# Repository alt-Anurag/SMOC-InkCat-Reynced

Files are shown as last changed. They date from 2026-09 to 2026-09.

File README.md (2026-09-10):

# InkCat — SMOC: A Modular, Self-Calibrating SCARA Robot

**A 5-DOF Self-Calibrating Modular SCARA bot built around a distributed embedded control network, continuous self-calibrating sensor fusion, and a simulation-first (Unity3D/ROS2) development pipeline.**

InkCat is a proof-of-concept precision robotic arm — not a hobby kit adaptation. Every layer of the stack was designed from scratch: the SolidWorks CAD kinematic chain, two custom PCB families (a supervisory controller and a distributed per-joint actuator board), a MATLAB/Simulink closed-loop control architecture validated against a Simscape Multibody model, and a Unity3D + ROS2 + OpenCV vision pipeline for perception-guided pick-and-place.

The long-term goal is ambitious by design: take this arm from a 3D-printed, PLA-bodied proof of concept to a rigid, millimeter-precision manipulator capable of tasks like PCB-grade component placement and even in-house PCB fabrication steps — the kind of precision work usually reserved for industrial SCARA arms costing orders of magnitude more.

<p align="center">
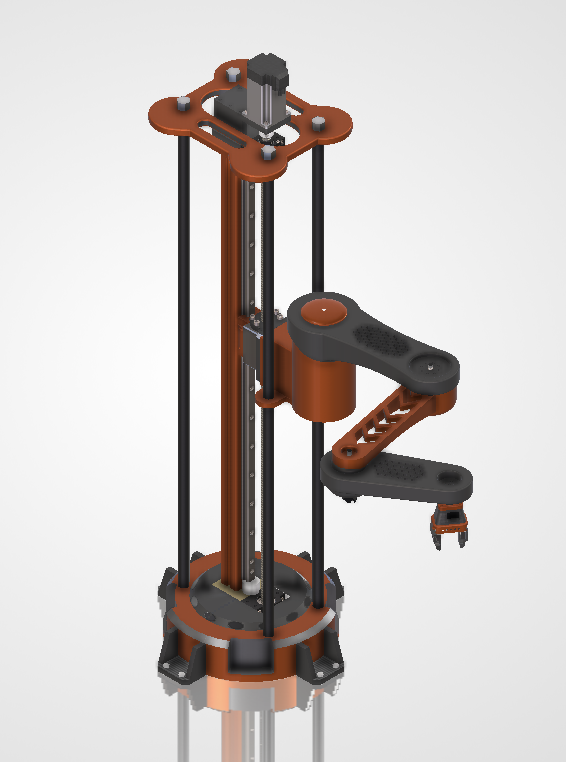
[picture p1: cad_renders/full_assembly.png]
InkCat full assembly render
  
</p>

---

## Table of Contents

- [Project Status](#project-status)
- [Why This Project Is Different](#why-this-project-is-different)
- [Tech Stack](#tech-stack)
- [System Architecture](#system-architecture)
- [Mechanical Design & CAD](#mechanical-design--cad)
  - [Kinematic Configuration](#kinematic-configuration)
  - [Structural Design](#structural-design)
  - [Material Strategy — Prototype vs. Deployment](#material-strategy--prototype-vs-deployment)
- [Electronics — Distributed Control Architecture](#electronics--distributed-control-architecture)
  - [Vesper ONE — Main Supervisory Controller](#vesper-one--main-supervisory-controller)
  - [FluxCruiser — Per-Joint Actuator Node](#fluxcruiser--per-joint-actuator-node)
  - [Sensor Fusion & Self-Calibration](#sensor-fusion--self-calibration)
- [Control Loop — MATLAB/Simulink Architecture](#control-loop--matlabsimulink-architecture)
- [Software & Perception Stack](#software--perception-stack)
- [Power Architecture](#power-architecture)
- [Repository Structure](#repository-structure)
- [How to Replicate / Build On This Project](#how-to-replicate--build-on-this-project)
- [Known Limitations](#known-limitations)
- [Roadmap](#roadmap)
- [Reference Material](#reference-material)
- [Credits](#credits)

---

## Project Status

This repository currently documents a **validated proof of concept**: the CAD kinematic design is complete and rendered, the control loop is validated in MATLAB/Simulink against a Simscape Multibody model, and both PCBs (Vesper ONE and FluxCruiser) are schematic-complete CAD designs. Firmware, ROS 2 nodes, and ML/vision scripts are **actively in development** and will be added to [`firmware/`](firmware/) as they're built and tested — see the disclaimers in each firmware subfolder for current status.

| Layer | Status |
|---|---|
| Mechanical CAD (SolidWorks) | ✅ Complete — full assembly modeled, rendered, exportable (STL/GLB/STEP) |
| Control loop (MATLAB/Simulink) | ✅ Validated in simulation (Simscape Multibody + EKF) |
| PCB schematics (Vesper ONE, FluxCruiser) | ✅ Schematic-complete, pre-fabrication |
| STM32 firmware | 🚧 In development — see [`firmware/stm32/`](firmware/stm32/) |
| ROS 2 / perception nodes | 🚧 In development — see [`firmware/ros2/`](firmware/ros2/) |
| ML / vision scripts | 🚧 In development — see [`firmware/ml_models/`](firmware/ml_models/) |
| Physical fabrication & assembly | 🔜 Planned next phase |

---

## Why This Project Is Different

* **Distributed embedded architecture:** Instead of putting the entire control stack on a single MCU, InkCat divides the workload between a supervisory STM32H743 (Vesper) and three STM32G431 actuator nodes (FluxCruiser). Vesper handles tasks such as state estimation and trajectory planning, while each actuator board runs the motor control locally for fast and predictable response.

* **Continuous self-calibration:** A key part of InkCat is keeping the robot's internal model accurate while it is operating. Joint encoders, a base-offset optical sensor, a magnetic Z-height encoder, and IMUs on the actuator nodes provide multiple measurements that can be combined through a recursive state estimator. This is intended to account for things such as mechanical offsets and drift without requiring the arm to be manually recalibrated between runs.

* **Simulation-first development:** The control system was developed and tested in MATLAB/Simulink using a Simscape Multibody model of the arm. This includes the Computed Torque Controller derived from the Euler-Lagrange formulation. In parallel, a Unity3D + ROS2 digital twin is used to test the vision and perception pipeline under different sensor and lighting conditions before moving to the physical setup.

* **Custom controller and actuator PCB architecture.** Vesper is the central controller board and handles the non-actuator sensors and external communication interfaces, including Ethernet, USB-C, and CAN-FD. The FluxCruiser boards handle the individual joints, with a dedicated Trinamic TMC9660 gate driver used for the motor-control stage.

* **Staged mechanical development:** The mechanical design is intended to work across different stages of development. The same CAD platform can first be used for an FDM-printed PLA prototype to validate the kinematics and control system, and later transition to a CNC-machined aluminum/steel version without requiring a complete structural redesign.

* **Designed around precision from the start:** InkCat is being developed with millimeter-level pick-and-place as a target, with applications such as PCB component handling and, eventually, automated PCB manufacturing processes in mind. Precision is therefore considered during the mechanical, sensing, and control design rather than being added after the basic arm is already functional.

---

## Tech Stack

| Layer | Choice |
|---|---|
| Mechanical CAD | SolidWorks 2026 |
| Supervisory Controller | STM32H743ZIT6 (Arm Cortex-M7, up to 480 MHz) — "Vesper ONE" |
| Actuator Node MCU (×3) | STM32G431 — "FluxCruiser" |
| Motor Driver / FOC Engine | Trinamic TMC9660 (×3, one per joint) |
| Z-Axis Stepper Driver | Trinamic TMC5160 (on Vesper) |
| Joint Encoders | SIKO AS5600 absolute magnetic encoder (×3) |
| Base Offset Sensor | PixArt PMW3389 high-precision optical motion sensor |
| IMUs | ADI ADIS16470-class / ICM-45686 6-axis (per actuator node) |
| Communication | CAN-FD (MAX33012EASA+), Ethernet (ADIN1200 PHY), USB Type-C, SPI, UART, I²C |
| Control Design | MATLAB/Simulink 2025, Simscape Multibody, Extended Kalman Filter |
| Control Law | Computed Torque Control (Euler-Lagrange), PD feedback, quintic polynomial trajectory planning, ADRC (planned for embedded target) |
| Simulation / Digital Twin | Unity3D + ROS 2 |
| Computer Vision | OpenCV (HSV segmentation, monocular projection) |
| PCB Design | Altium Designer 2025 |
| Motor / Magnetics Design | Ansys Maxwell |
| Prototype Material | PLA (FDM) / Carbon-Fiber-Reinforced PLA |
| Deployment Material | Aluminium 6061-T6 (links, column), steel (base, joint shafts, fasteners) |

---

## System Architecture

```
                         ┌─────────────────────────────────────────┐
                         │      VESPER ONE (STM32H743ZIT6)         │
   Vision (Ethernet/USB) │      Supervisory Controller             │
   ─────────────────────►│  • Sensor fusion (EKF/EWMA)             │
                         │  • Self-calibration engine              │
   PMW3389 (base offset) │  • Inverse kinematics                   │
   ─────────────────────►│  • Quintic trajectory planning          │
                         │  • ADRC / high-level closed-loop control│
   MSC500 (Z-height)     │  • TMC5160 — Z-axis stepper drive       │
   ─────────────────────►│                                         │
                         └───────────────┬─────────────────────────┘
                                         │ CAN-FD
                ┌────────────────────────┼────────────────────────┐
                ▼                        ▼                        ▼
    ┌─────────────────────┐    ┌────────────────────┐    ┌────────────────────┐
    │  FluxCruiser #1     │    │  FluxCruiser #2    │    │  FluxCruiser #3    │
    │  (Shoulder)         │    │  (Elbow)           │    │  (Wrist)           │
    │  STM32G431 + TMC9660│    │ STM32G431 + TMC9660│    │ STM32G431 + TMC9660│
    │  + IMU + Encoder    │    │ + IMU + Encoder    │    │ + IMU + Encoder    │
    └─────────┬───────────┘    └─────────┬──────────┘    └─────────┬──────────┘
              ▼                          ▼                         ▼
         BLDC Motor                BLDC Motor              BLDC Motor / Gripper
         (Shoulder)                 (Elbow)                  (Wrist + Gripper)
```

Vesper is the single point of contact for every non-actuator sensor and all external communication — no other board in the system carries a direct external connection. The three FluxCruiser nodes handle only their local joint's current/velocity/position loop and stream raw encoder/IMU data back to Vesper over CAN-FD as ground-truth feedback, independent of what was actually commanded.

---

## Mechanical Design & CAD

<p align="center">
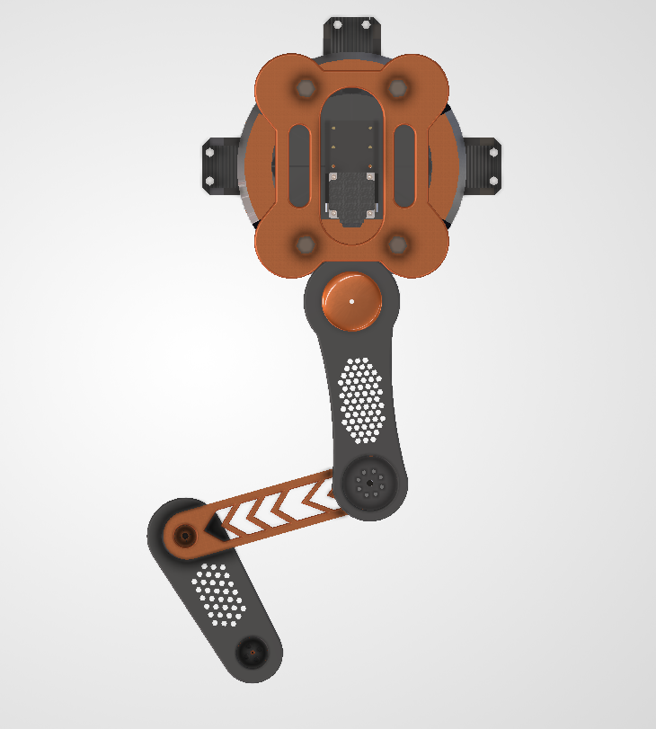
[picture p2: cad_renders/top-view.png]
Top view of arm reach
  
  &nbsp;&nbsp;
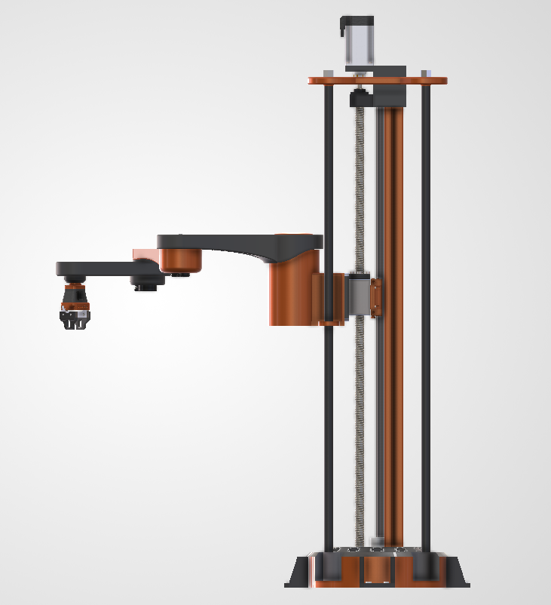
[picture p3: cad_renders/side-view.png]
Side view of column
  
</p>

### Kinematic Configuration

InkCat is a custom 5-degree-of-freedom desktop SCARA following a **Prismatic–Revolute–Revolute–Revolute–Prismatic (P-R-R-R-P)** joint chain. This is the classic SCARA layout — high stiffness along the vertical Z-axis, selective compliance in the horizontal X-Y plane — extended with a wrist revolute joint and a rack-and-pinion parallel-jaw gripper for full end-effector orientation and controlled grasp force.

| Joint | Type | Actuation | Primary Function |
|---|---|---|---|
| DOF 1 — Z Axis | Prismatic | Lead-screw linear actuator + linear guide rail | Vertical approach, pickup, placement, height adjust |
| DOF 2 — Shoulder | Revolute | BLDC motor, vertical axis | Primary arm sweep, workspace coverage |
| DOF 3 — Elbow | Revolute | BLDC motor, vertical axis | Reach extension, fine positioning |
| DOF 4 — Wrist | Revolute | BLDC motor, vertical axis | End-effector orientation, placement alignment |
| DOF 5 — Gripper | Prismatic | Rack-and-pinion, parallel jaws | Grasp, release, precision manipulation |

The resulting workspace is cylindrical: vertical reach is set by the Z-axis stroke, and horizontal reach by the two-link arm's combined length — giving the arm the SCARA-defining trait of being naturally forgiving for vertical insertion tasks (PCB/connector-style assembly) while remaining precisely positioned laterally.

### Structural Design

<table>
  <tr>
    <td width="260" align="center">
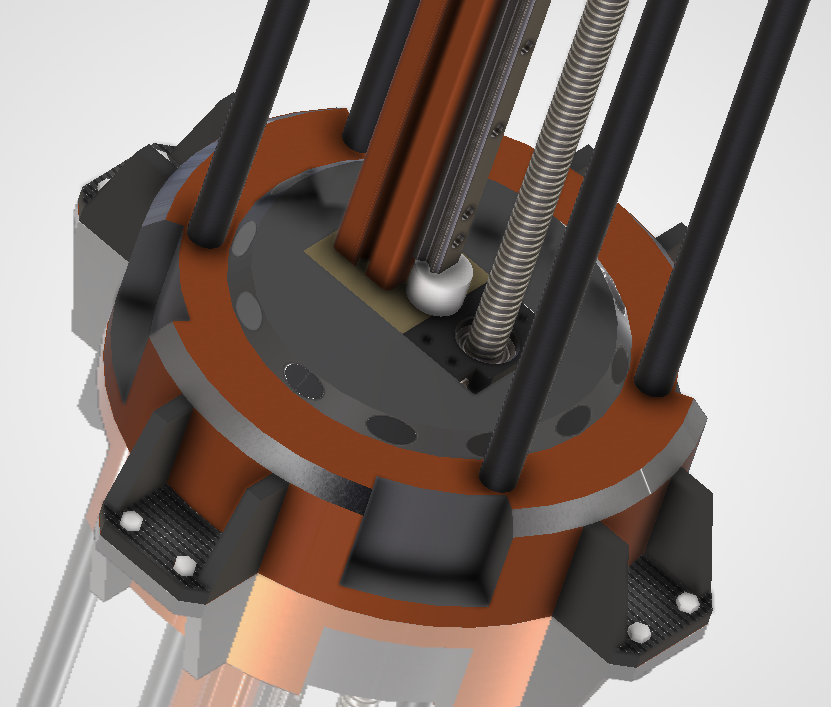
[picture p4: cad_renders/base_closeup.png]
      <br>
      <sub><b>Base & Z-column</b></sub>
    </td>
    <td>The base is an enclosed housing with a removable cover, internally compartmentalized for the PCB, motor drivers, wiring harnesses, and power electronics. Keeping all electronics inside the base lowers the overall center of gravity and keeps the arm's kinematic assembly above it undisturbed during maintenance. The vertical column integrates the linear guide rail, lead screw, drive motor enclosure, and sliding carriage into one rigid structural member — it has to carry axial load and resist the bending moment of the fully extended arm simultaneously, which drove the choice of a ribbed, large-cross-section profile.</td>
  </tr>
  <tr>
    <td width="260" align="center">
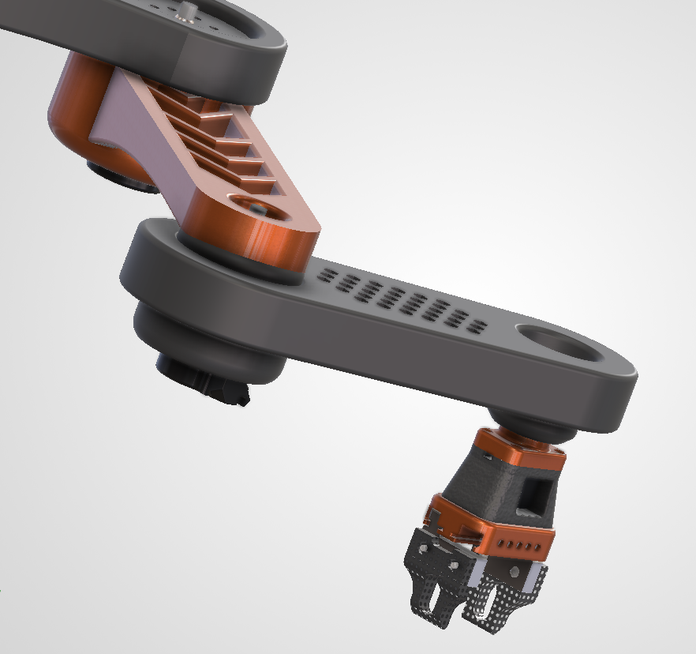
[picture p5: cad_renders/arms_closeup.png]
      <br>
      <sub><b>Upper arm & fore-arm links</b></sub>
    </td>
    <td>Both arm links use a hollow, ribbed shell geometry with rounded edges and a deliberately large bending depth. This is a weight-optimization strategy — removing material from the neutral bending axis while retaining depth preserves stiffness-to-weight ratio, which directly reduces the rotational inertia the shoulder and elbow BLDC motors have to overcome during acceleration.</td>
  </tr>
  <tr>
    <td width="260" align="center">
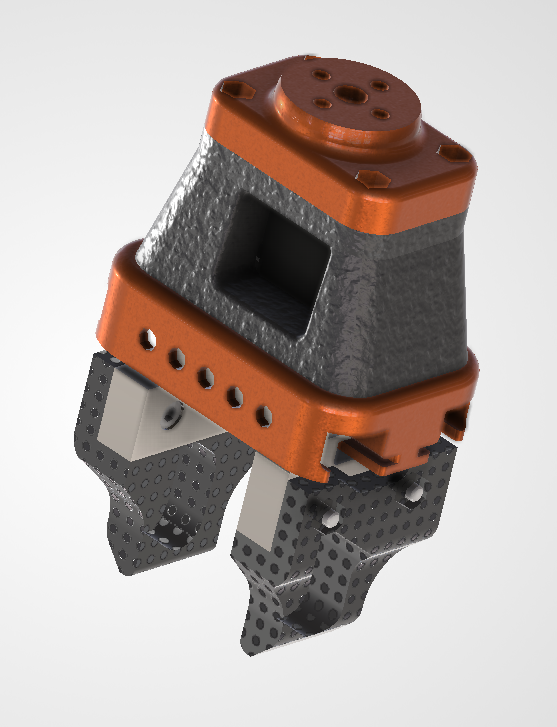
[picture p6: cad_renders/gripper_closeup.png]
      <br>
      <sub><b>Wrist & gripper</b></sub>
    </td>
    <td>The wrist is a compact rotational stage that orients the gripper before grasp. The end effector is a parallel-jaw gripper actuated through a rack-and-pinion mechanism, chosen for symmetric jaw travel, positive mechanical engagement, and repeatable grip force — suited to PCB handling, small mechanical parts, and lab-sample manipulation.</td>
  </tr>
  <tr>
    <td width="260" align="center">
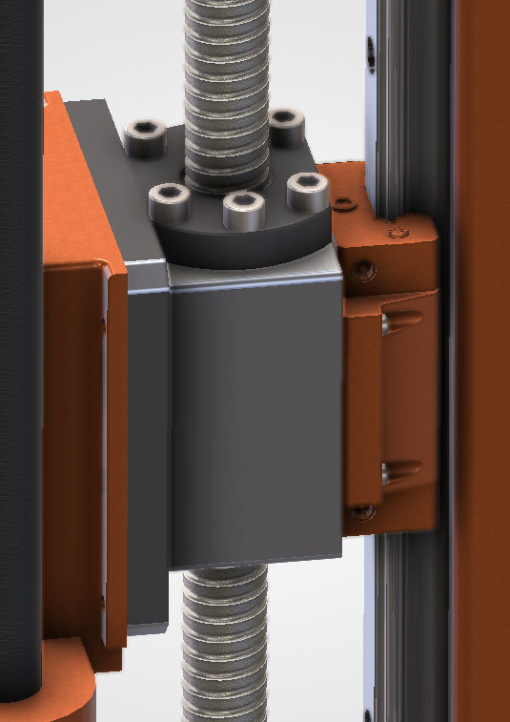
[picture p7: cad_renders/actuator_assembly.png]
      <br>
      <sub><b>Z-axis actuator detail</b></sub>
    </td>
    <td>Close-up of the lead-screw carriage and linear guide interface — the load path the entire arm hangs off of. Precision here directly bounds the vertical repeatability of the whole manipulator.</td>
  </tr>
</table>

**Design language:** the platform deliberately follows a hidden-actuator, minimal-fastener visual language — motor housings enclosed, fillets consistent across every structural part, symmetric arm proportions, and an orange-and-black color scheme meant to read as a finished product rather than a lab rig.

**Manufacturability:** the CAD is built as a serviceable modular assembly — independently swappable link components, fully enclosed electronics, and internal cable routing through the column and links — suited to FDM/SLA printing of the structural shells combined with off-the-shelf linear guides, lead screws, bearings, and fasteners for the motion-critical interfaces.

### Material Strategy — Prototype vs. Deployment

| Phase | Structural Components | Motion / Hardware Components |
|---|---|---|
| **Phase 1 — Prototype / Testing** | PLA (FDM 3D-printed): base shell, links, wrist housing, gripper jaws | Steel lead screw & linear rail, standard bearings, off-the-shelf BLDC motors and fasteners |
| **Phase 2 — Final Deployment** | Aluminium 6061-T6 (links & column, machined/CNC); steel (high-load base and joint interfaces) | Precision-ground steel lead screw, hardened linear rails, rubber gripper-jaw inserts, sealed bearings |

PLA is used for the initial prototype because of its dimensional stability, ease of printing, low cost, and adequate stiffness for validating kinematics and control-loop tracking without committing to expensive tooling. Deployment shifts structural links and the column to machined aluminum 6061-T6 for strength-to-weight and corrosion resistance, while high-load interfaces move to steel for durability under repeated cyclic loading. Rubber inserts at the gripper jaw contact faces increase grip friction and give compliant, damage-safe handling of delicate PCB and electronic payloads.

| Parameter | Value |
|---|---|
| Overall footprint (base ⌀) | 300 ± 5 mm |
| Total height (Z fully retracted) | 100 ± 5 mm |
| Maximum horizontal reach | 505 ± 5 mm |
| Maximum payload (PLA prototype build) | 1.25 ± 0.05 kg |
| Maximum payload (aluminum deployment build) | 11.50 ± 0.25 kg |

*(Dimensional figures above are the CAD-derived design targets from the current proof-of-concept model.)*

---

## Electronics — Distributed Control Architecture

### Vesper ONE — Main Supervisory Controller

<p align="center">
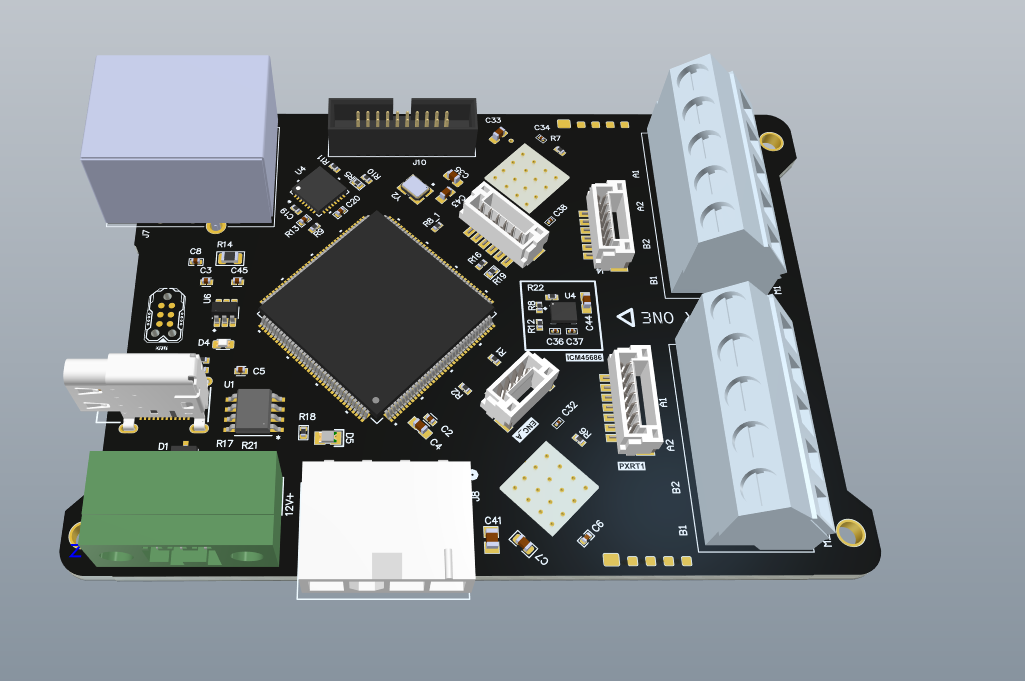
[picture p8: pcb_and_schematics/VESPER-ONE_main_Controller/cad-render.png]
Vesper ONE CAD render
  
</p>

Vesper ONE is the single supervisory board in the system — every non-actuator sensor terminates here, and no other board carries a direct external connection. It's built around an **STM32H743ZIT6**, whose Arm Cortex-M7 core runs up to 480 MHz with a double-precision FPU and hardware Chrom-ART acceleration, backed by up to 2 MB flash / 1 MB SRAM — enough headroom to run sensor fusion, inverse kinematics, and trajectory generation without offloading that work to the actuator nodes.

Alongside the H743, Vesper integrates a **Trinamic TMC5160** stepper driver for the Z-axis lead-screw motor. Its StealthChop2 voltage-mode chopper keeps the vertical axis quiet and low-vibration, 256-step MicroPlyer interpolation smooths motion from coarse step inputs, and integrated stallGuard4 sensorless load detection allows automatic end-of-travel detection — meaning Z-axis recalibration doesn't need physical limit switches.

External communication runs through an **ADIN1200** Ethernet PHY (vision data) and a **MAX33012EASA+** CAN-FD transceiver (actuator/encoder/IMU traffic), plus USB Type-C, SPI, UART, and I²C.

<p align="center">
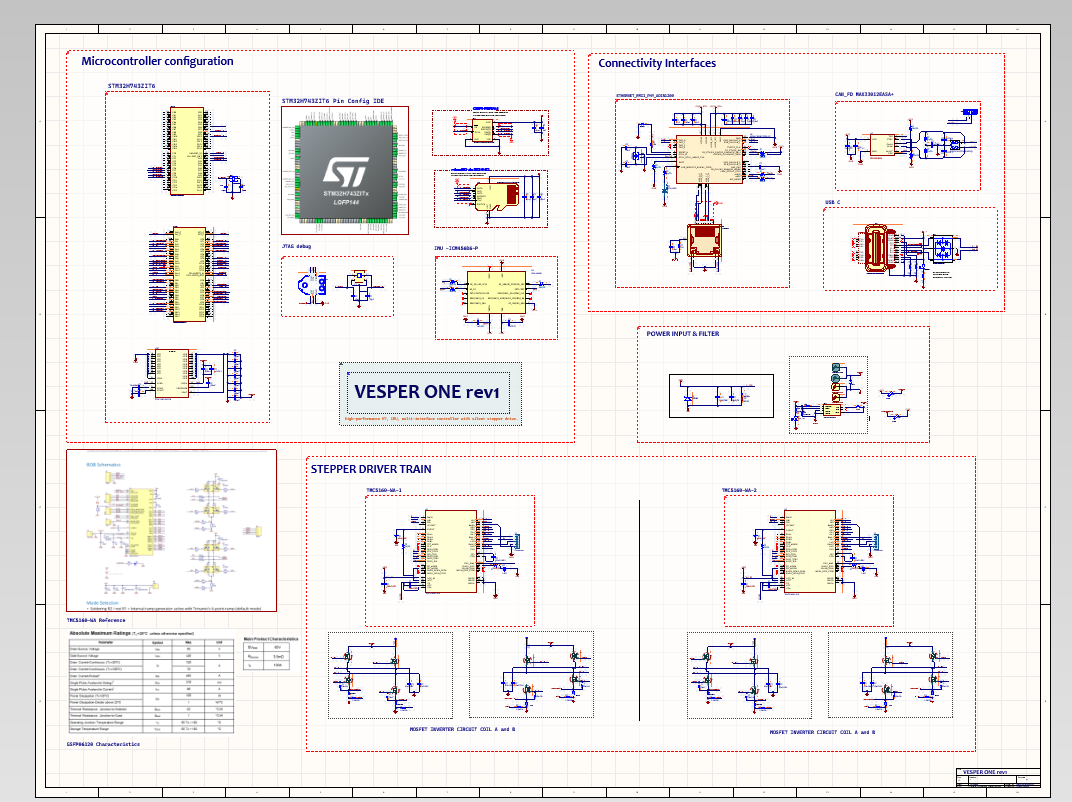
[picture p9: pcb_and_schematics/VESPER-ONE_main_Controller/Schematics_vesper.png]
Vesper ONE schematic
  
</p>

<p align="center"><sub>Vesper ONE schematic — microcontroller configuration, connectivity interfaces (Ethernet/CAN-FD/USB-C), power input & filtering, and the dual-TMC5160 stepper driver train.</sub></p>

### FluxCruiser — Per-Joint Actuator Node

<p align="center">
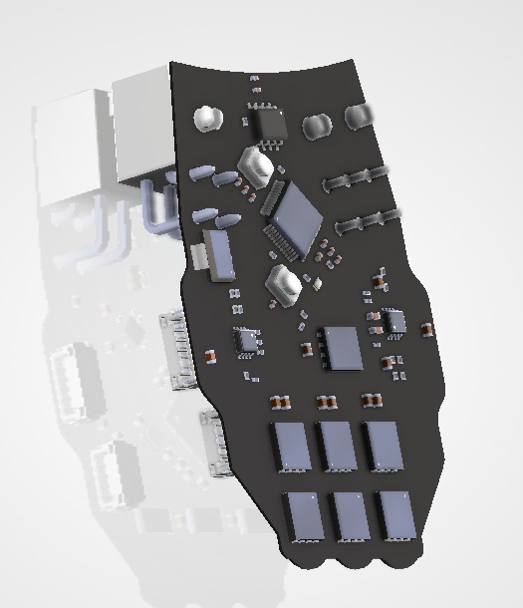
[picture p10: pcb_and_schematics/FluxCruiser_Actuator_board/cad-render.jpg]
FluxCruiser CAD render
  
  &nbsp;&nbsp;
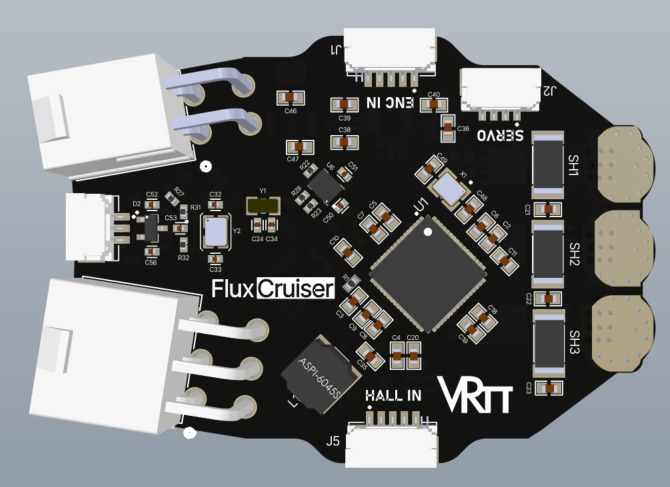
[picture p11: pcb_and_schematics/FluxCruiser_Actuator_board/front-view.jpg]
FluxCruiser front view
  
</p>

FluxCruiser is the distributed motor-control PCB deployed at each of the arm's three kinematic joints (shoulder, elbow, wrist), offloading Field-Oriented Control math to a dedicated gate driver for deterministic, low-latency motion control local to the joint.

**Core processing:** an **STM32G431** manages kinematic trajectories, CAN-FD communication, and sensor data, while a **Trinamic TMC9660** handles FOC phase mathematics and motor timing — the two linked via a high-speed SPI bus.

**Power:** motor power arrives via a 48V Molex connector rated to 27A, with an isolated 12V flyback rail for logic and gate drivers. An AMS1117-3.3 LDO supplies the STM32G431's 3.3V rail; the TMC9660's internal LDO generates an auxiliary 5V rail for sensors.

**Power stage & safety:** the 3-phase inverter uses over-specced Goodark 100V/80A MOSFETs for thermal headroom against inductive spikes, and a hardware brake chopper dumps regenerative energy into a shunt resistor to protect the 48V bus from overvoltage during sharp decelerations.

**Sensing & telemetry:** each node carries an onboard **ICM-45686** 6-axis IMU for gravitational compensation and vibration damping, plus JST-GH interfaces for Hall-effect sensors and encoders, linking back to Vesper via CAN-FD.

### Sensor Fusion & Self-Calibration

The core technical contribution of this project is a **continuous self-calibration layer** that keeps the robot's internal state accurate under drift, wheel slip, and mechanical offset — without a manual recalibration step between runs. Four independent sensing sources feed a recursive state estimator running on Vesper's STM32H743:

- **Joint & actuator encoders (all three nodes)** — each TMC9660 is direct-coupled to its local encoder for closed-loop current/velocity/position control; raw counts also stream to Vesper as ground-truth joint feedback, independent of what was commanded.
- **PMW3389 optical motion sensor — base offset** — functions like a high-speed optical mouse sensor, imaging the surface beneath the base and cross-correlating successive frames to compute incremental X-Y displacement, accumulating any planar offset or rotation caused by wheel slip or a mechanical bump.
- **MSC500 magnetic encoder — height measurement** — a non-contact absolute magnetic linear encoder along the Z-axis lead-screw column, giving a wear-free absolute height readout rather than an incremental count that can drift.
- **IMU (per actuator node)** — linear acceleration and angular velocity per joint, for orientation, base attitude, and dynamic motion state.
- **Vision system (external)** — object coordinates from the vision pipeline, transmitted over Ethernet or USB-C.

Vesper compares the expected carriage height (computed from lead-screw pitch and stepper turns) against the MSC500's measured height; any discrepancy beyond a set threshold feeds directly into the actuator's FOC loop to compensate for missed steps, backlash, or mechanical drift before the next motion command. Concurrently, an EKF/EWMA filter fuses all five data streams into a single corrected state estimate, so mechanical errors are actively compensated rather than propagating downstream into inverse kinematics and trajectory planning.

---

## Control Loop — MATLAB/Simulink Architecture

<p align="center">
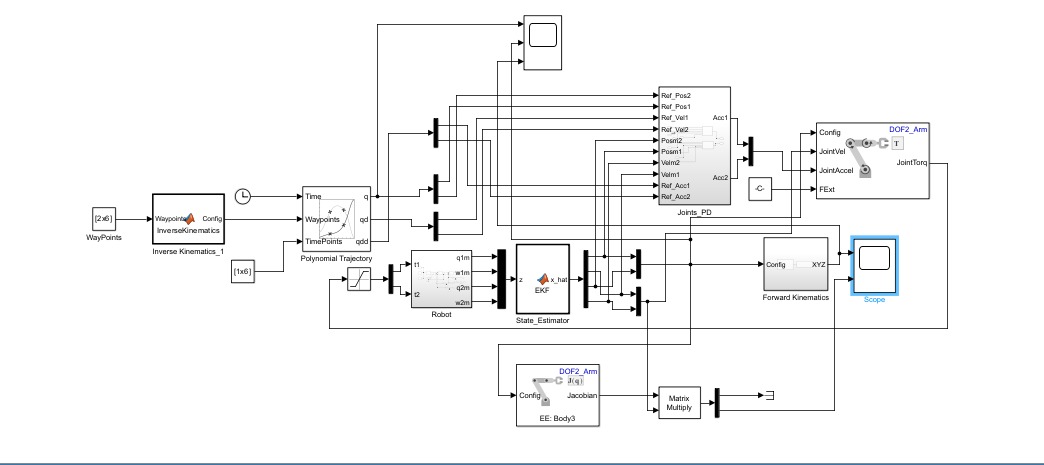
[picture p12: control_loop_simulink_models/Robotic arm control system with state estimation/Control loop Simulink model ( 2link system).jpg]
Simulink control loop model
  
</p>

The MATLAB/Simulink model implements a complete closed-loop control architecture, validated before any hardware commitment:

1. **Waypoint definition** — predefined Cartesian coordinates with timestamps define the desired end-effector path.
2. **Inverse kinematics** — Cartesian waypoints are converted to joint-space waypoints analytically.
3. **Quintic polynomial trajectory planning** — generates smooth joint position, velocity, and acceleration profiles with guaranteed continuity, reducing mechanical stress and actuator torque peaks.
4. **Simscape Multibody simulation** — the planned trajectory drives a full multibody dynamic model; simulated encoder measurements are processed through an **Extended Kalman Filter** to fuse model predictions with sensor data for accurate joint state estimates.
5. **PD feedback + Computed Torque Control** — position/velocity errors from the EKF-estimated state versus the reference trajectory feed a tuned PD controller to generate desired joint accelerations, which are supplied to an Inverse Dynamics block implementing **Computed Torque Control** (Euler-Lagrange formulation) — compensating for inertia, Coriolis, centrifugal, and gravitational effects to compute the actual required actuator torques.
6. **Forward kinematics & Jacobian** — estimated joint states are run back through forward kinematics for real-time end-effector position/velocity monitoring and validation.

<p align="center">
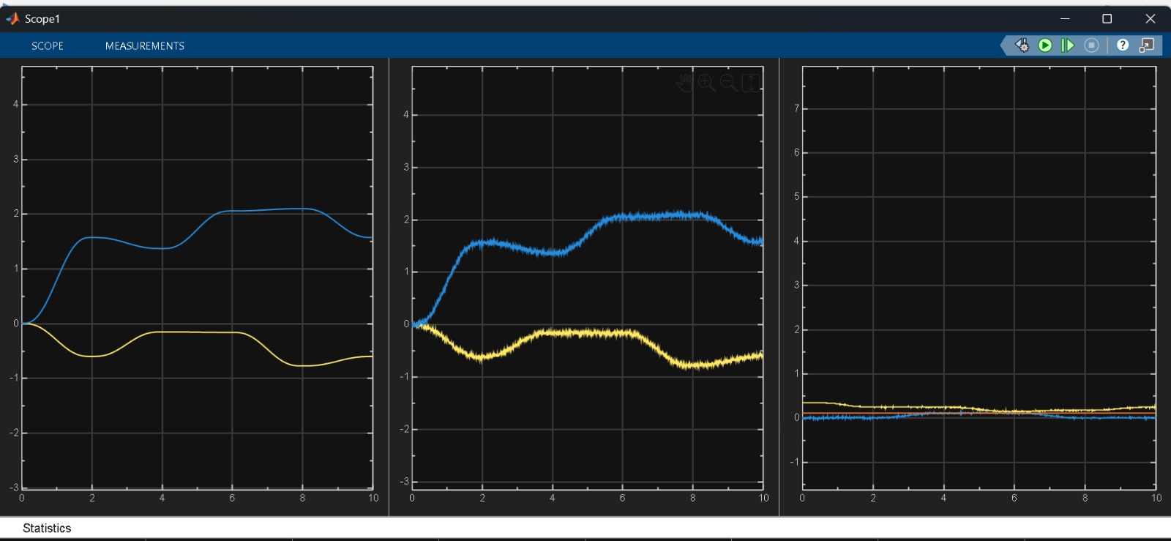
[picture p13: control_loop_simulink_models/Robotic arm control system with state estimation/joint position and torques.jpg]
Joint trajectory feedback response
  
  &nbsp;&nbsp;
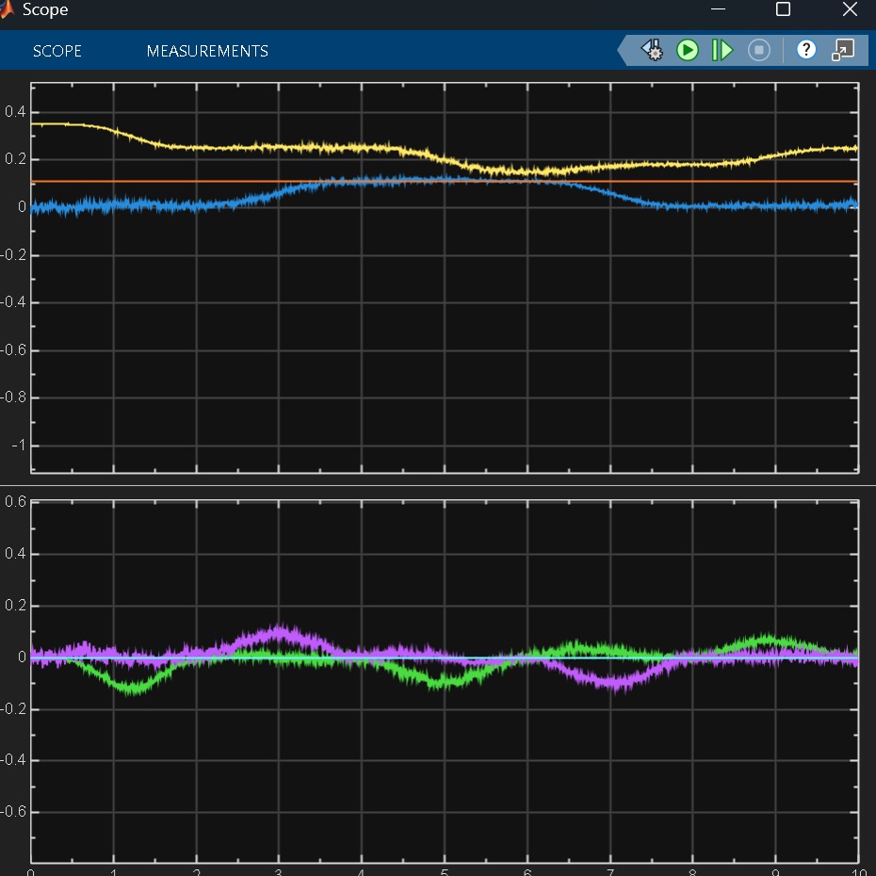
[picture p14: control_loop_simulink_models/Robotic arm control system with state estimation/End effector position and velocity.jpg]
End-effector position and velocity
  
</p>

<p align="center"><sub>Left: joint trajectory feedback response. Right: end-effector position/velocity profile from the closed-loop simulation.</sub></p>

This architecture — trajectory planning, state estimation, feedback control, dynamic compensation, and kinematic analysis unified into one closed loop — closely mirrors the control strategy used in real industrial manipulators, and is built as a scalable foundation for the eventual embedded (STM32) implementation, where the plan is to run **ADRC (Active Disturbance Rejection Control)** as the primary control law.

A separate Hardware-in-the-Loop validation of the Field-Oriented Control stage is documented in [`control_loop_simulink_models/HIL validation of Field Oriented Control on Simulink_azharjawed (1).pdf`](control_loop_simulink_models/HIL%20validation%20of%20Field%20Oriented%20Control%20on%20Simulink_azharjawed%20%281%29.pdf).

---

## Software & Perception Stack

<p align="center">
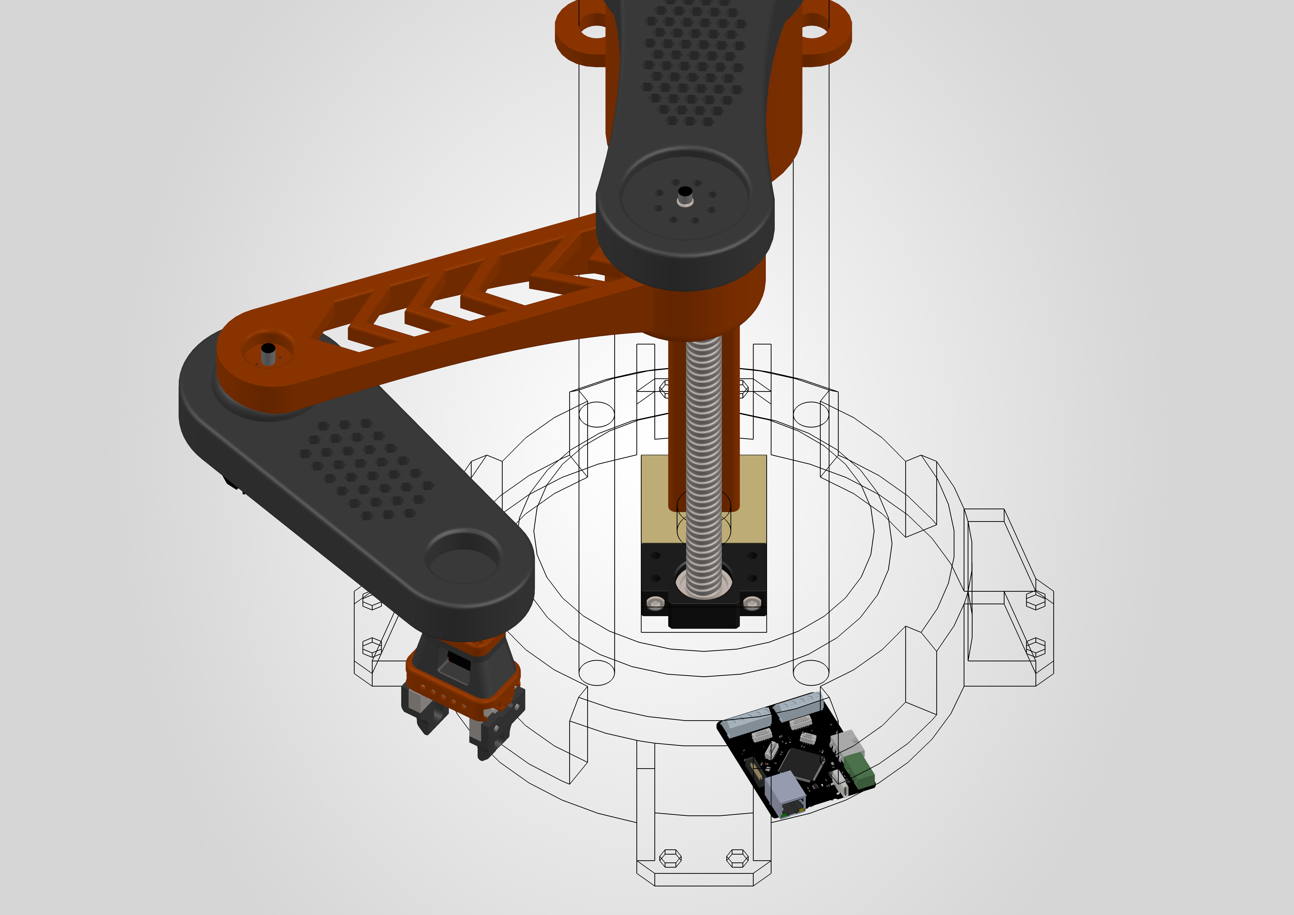
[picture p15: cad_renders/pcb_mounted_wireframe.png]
PCB and electronics integration wireframe
  
</p>

The software architecture is intentionally modular — perception, motion planning, and control live in independent nodes so any one layer (e.g. a vision algorithm) can be swapped without touching the others.

As a proof of concept, a **Unity3D-based digital twin** integrated with **ROS 2** replicates the SCARA arm's behavior, letting motion, perception, interaction, and control algorithms be tested in a realistic virtual environment before deployment to real hardware. The simulation features a fixed overhead RGB camera, a customizable ground plane, and simulated sensor noise / dynamic lighting variation — deliberately introduced to stress-test the perception pipeline against real-world conditions like glare and shadows before it ever sees a physical camera.

**Vision pipeline:** raw camera frames are published to ROS 2 (`/camera/image_raw`), where an OpenCV node performs HSV color segmentation to isolate targets, applies morphological filtering and contour extraction to refine object boundaries, and generates bounding boxes for center-coordinate calculation. Monocular projection then maps these image coordinates to world (X, Y, Z) coordinates — avoiding the cost of depth hardware while feeding the motion planner accurate spatial data for real-time pick-and-place.

This decoupled structure — simulation, perception, and control stack all communicating over identical ROS 2 topics/protocols regardless of whether the source is simulated or real — is what de-risks the eventual jump from the Unity3D digital twin to physical hardware.

---

## Power Architecture

The system is powered from a **220VAC mains input**, conditioned through a Power Factor Correction stage, then split into two isolated DC-DC domains to minimize electromagnetic interference:

- **48V DC bus** (1kW LLC resonant converter) — drives the primary BLDC motors and the Z-axis stepper motor.
- **12V/120W isolated flyback rail** — dedicated logic power for the main control boards, communication interfaces, and sensors, isolated from motor-switching transients.

Local low-dropout regulators derive 3.3V from the 12V rail for the STM32H7/STM32G4 logic levels. This multi-stage isolation — separating the high-voltage/high-current actuator path from the low-voltage, noise-sensitive logic path — mitigates back-EMF and high-frequency switching noise risks. A star-ground topology on the FluxCruiser PCB references both the 48V and 12V rails to a single common ground point, avoiding ground-loop noise between domains.

---

## Repository Structure

```
InkCat-SMOC/
├── README.md
│
├── cad_files/
│   ├── final_scara_prototype.STL
│   ├── final_scara_prototype_1.glb
│   ├── SolidWorks_Package (2026 version compatible only)/   # Full native .SLDPRT/.SLDASM + STEP source files
│   └── readme.txt
│
├── cad_renders/
│   ├── full_assembly.png
│   ├── top-view.png / side-view.png / corner-top-view.png
│   ├── base_closeup.png / arms_closeup.png / gripper_closeup.png / actuator_assembly.png
│   ├── first-link_closeup.png / esc_arm_wireframe.jpg
│   └── pcb_mounted_wireframe.png
│
├── pcb_and_schematics/
│   ├── VESPER-ONE_main_Controller/
│   │   ├── Schematics_vesper.png
│   │   ├── Board_connections.png
│   │   ├── STM32H743 pin Config for Vesper.jpg
│   │   └── front-view.png / back-view.png / side-view.png / cad-render.png
│   └── FluxCruiser_Actuator_board/
│       └── front-view.jpg / back-view.jpg / side-view.jpg / cad-render.jpg
│
├── control_loop_simulink_models/
│   ├── HIL validation of Field Oriented Control on Simulink_azharjawed (1).pdf
│   └── Robotic arm control system with state estimation/
│       ├── Control loop Simulink model ( 2link system).jpg
│       ├── joint position and torques.jpg
│       └── End effector position and velocity.jpg
│
├── explainer_video/
│   ├── Part 1_ Intro.mp4
│   └── Part 2_ A Deep Dive.mp4
│
├── references_and_bibliography/
│   ├── InkCat-SMOC_POC.pdf                 # Full proof-of-concept document
│   └── research_papers_refered.txt
│
└── firmware/                                # ⚠️ In progress — see disclaimers below
    ├── stm32/       # Vesper + FluxCruiser embedded firmware
    ├── ros2/        # Perception nodes, sim bridge, motion interface
    └── ml_models/   # Vision scripts, calibration tools, future ML models
```

> **Note on the `firmware/` folder:** this is new, and every subfolder (`stm32/`, `ros2/`, `ml_models/`) contains only a `README.md` disclaimer for now. None of the firmware, ROS 2 nodes, or vision scripts described in this document are committed yet — they're actively being developed and tested on evaluation hardware. Each subfolder will be populated incrementally as its contents are validated; check the disclaimer in each folder for current status before assuming any code there is functional.

---

## How to Replicate / Build On This Project

1. **Review the full POC document** — [`references_and_bibliography/InkCat-SMOC_POC.pdf`](references_and_bibliography/InkCat-SMOC_POC.pdf) is the authoritative design document this README is based on; read it first for the complete reasoning behind every architectural decision.
2. **Open the CAD.** If you have SolidWorks 2026, open `final_scara_prototype.SLDASM` inside the `SolidWorks_Package` folder for the full native, editable assembly. Otherwise, use `final_scara_prototype.STL` or `.glb` with any standard viewer (Windows 3D Viewer, Blender, an online GLB viewer, etc.) for a non-editable but fully visual reference.
3. **Study the schematics.** Both PCB schematics (Vesper ONE, FluxCruiser) are provided as high-resolution exports under `pcb_and_schematics/`. These are proof-of-concept schematics — not yet fabricated Gerbers — so treat them as a reference design rather than a drop-in fab-ready package.
4. **Reproduce the control loop.** The MATLAB/Simulink model architecture is described in full under [Control Loop](#control-loop--matlabsimulink-architecture) — a from-scratch rebuild following that structure (Inverse Kinematics → Quintic Trajectory Planner → Simscape Multibody → EKF → PD + Computed Torque Control → Forward Kinematics) will reproduce the validated closed-loop behavior shown in the referenced Simulink screenshots.
5. **Source the components.** The full bill of materials and required eval-kits are listed in [Tech Stack](#tech-stack) — key long-lead items are the TMC9660 and TMC5160 motor-control ICs and the ADI sensor/communication parts (ADIS16470-class IMU, ADIN1200 PHY, MAX33012E CAN-FD transceiver), which the original team notes can be hard to source in some regions and are worth ordering early.
6. **Watch the explainer videos** — `explainer_video/Part 1_ Intro.mp4` and `Part 2_ A Deep Dive.mp4` walk through the system in more conversational detail than the written docs.
7. **Track firmware progress** in [`firmware/`](firmware/) — this is where STM32 code, ROS 2 nodes, and vision scripts will land as they're completed and tested. Nothing there yet is guaranteed to run.

---

## Known Limitations

Carried over directly from the project's own POC self-assessment, since these are real, current constraints rather than resolved issues:

- **Component sourcing** — ADI/Trinamic motor-control ICs are not always readily available in every market, which can affect the actuator development timeline even after eval-module validation is complete.
- **IMU calibration** — the onboard IMUs show fluctuations under vibration and require calibration before their data can be trusted in the fusion loop.
- **PMW3389 base-offset calibration** is non-trivial and still being tuned.
- **Fusion/control overhead** — the self-error-correction loop (currently planned around a UKF for state estimation with ADRC as the primary control algorithm) adds significant tuning and firmware-testing overhead beyond a simpler PID approach.
- **Mechanical stress concentration** — the middle link currently carries less material and is a higher-stress point; material testing is needed to balance speed against structural limits before finalizing the aluminum deployment design.
- **Direct-drive actuation** is still being studied and isn't yet proven for the in-house actuator design.
- **Vision pipeline latency** — camera-based detection and mapping currently has latency that needs to be reduced for reliable real-time state prediction during fast motion.

---

## Roadmap

**Near-term (embedded bring-up):**
- Validate control logic on evaluation modules (TMC9660-STP-EVKIT, TMC5160-BOB, CAN-FD/Ethernet eval boards) before committing to custom silicon-level bring-up.
- Design, fabricate, and bring up the actual Vesper ONE and FluxCruiser PCBs.
- Develop in-house BLDC actuators around the TMC9660 FOC architecture and tune the drive stack.
- Get the self-calibrating sensor fusion loop (UKF + ADRC) running on real hardware, not just in simulation.

**Long-term (precision & deployment):**
- Push the self-calibrating actuator system to real deployment conditions and mature the vision-based precision system to production readiness.
- Refine SCARA link materials for the best strength-to-weight ratio and fastest possible arm movement.
- Improve mechanical precision through gripper redesign and control-loop refinement, targeting **millimeter-level repeatability** — the prerequisite for the project's headline long-term goal of PCB-grade component placement and, eventually, in-house PCB manufacturing steps.
- Develop a UI for bot control and real-time monitoring.
- Once the core system is proven reliable, open the platform up for wider use or publish findings.

---

## Reference Material

Primary datasheets and research referenced during design (full list in [`references_and_bibliography/research_papers_refered.txt`](references_and_bibliography/research_papers_refered.txt)):

- [Trinamic TMC5160 datasheet](https://www.analog.com/en/products/tmc5160.html) — Z-axis stepper driver
- [Trinamic TMC9660 datasheet](https://www.analog.com/en/products/tmc9660.html) — per-joint FOC driver
- [ADIS16470 datasheet](https://www.analog.com/en/products/adis16470.html) — IMU reference
- [ADIN1200 datasheet](https://www.analog.com/en/products/adin1200.html) — industrial Ethernet PHY
- [MAX33012E datasheet](https://www.analog.com/en/products/max33012e.html) — CAN-FD transceiver
- [STM32H743/753 product page](https://www.st.com/en/microcontrollers-microprocessors/stm32h743-753.html) — Vesper's supervisory MCU
- "Active Disturbance Rejection Control of a SCARA Robot Arm" — ResearchGate, referenced for the planned embedded ADRC control law
- "Two Error Models for Calibrating SCARA Robots based on the MDH Model" — ResearchGate, referenced for the self-calibration approach
- Additional ScienceDirect / DOI references on robot calibration and precision manufacturing — see the full bibliography file linked above

A compiled QR-code link to the full research paper set referenced during ideation is also included on the cover page of the POC document.

---

## Credits

Proposed and developed by **Anurag Kumar Jha, Azhar Jawed, Ansh Wadhera, Vighnesh R Pai, and Suyash Raiswal** — B.Tech undergraduates, Delhi Technological University.

Submitted as part of **Anveshan 2026** under the project name *InkCat — Resynced*, sub-titled *SMOC: A Modular, Self-Calibrating SCARA Robot Design*.

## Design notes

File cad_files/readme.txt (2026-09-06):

use any .stl/ .glb viewer to open cad or if solidworks (2026 compatible only) available then use .sldasm/ .sldprt files to view the model.

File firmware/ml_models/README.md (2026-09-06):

# ML Models & Python Scripts — Vision & Precision Pipeline

> ⚠️ **Work in progress.** This folder is a placeholder. Python tooling for the vision/perception pipeline (color/object detection, camera calibration, coordinate-mapping validation) and any future ML-based precision or defect-detection models are still in development. Code will be committed here incrementally as each script or model is tested against the simulation and, later, real camera data.

## Planned contents

- `vision/` — Python/OpenCV scripts for HSV-based object detection, prototyping ahead of the ROS 2 node port.
- `calibration/` — Camera intrinsic/extrinsic calibration scripts, monocular-projection accuracy validation.
- `sim_tools/` — Scripts for generating synthetic training/test data from the Unity3D simulation.
- `models/` — Any trained model weights and training scripts added as the precision/defect-detection roadmap (see root README's Future Work section) is implemented.

No functional code is guaranteed to run yet. If you're cloning this repo to reference the *design*, see the root [`README.md`](../../README.md) and the POC document instead — this folder will be updated as modules pass testing.

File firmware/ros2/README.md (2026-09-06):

# ROS 2 — Perception & Motion Interface

> ⚠️ **Work in progress.** This folder is a placeholder. The ROS 2 nodes described in the project POC (Unity3D digital-twin bridge, `/camera/image_raw` publisher, OpenCV-based HSV segmentation and bounding-box detection, monocular coordinate-projection node) are still being built and tested against the simulation environment. Code will be committed here incrementally as each node is validated — expect this folder to be empty or partially populated until then.

## Planned contents

- `perception/` — OpenCV pipeline node: HSV segmentation, morphological filtering, contour extraction, bounding-box → world-coordinate projection.
- `sim_bridge/` — Unity3D ↔ ROS 2 topic bridge (camera feed, scene object ground-truth).
- `motion_interface/` — ROS 2 ⇄ CAN-FD bridge node forwarding trajectory commands to the Vesper main controller.
- `launch/` — launch files tying the above together for the digital-twin proof of concept.

No functional code is guaranteed to run yet. If you're cloning this repo to reference the *design*, see the root [`README.md`](../../README.md) and the POC document instead — this folder will be updated as modules pass testing.

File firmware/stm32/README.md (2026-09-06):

# STM32 Firmware — Vesper Main Controller & FluxCruiser Actuator Nodes

> ⚠️ **Work in progress.** This folder is a placeholder. Firmware for both the STM32H743-based Vesper main controller and the STM32G431-based FluxCruiser actuator nodes is currently being developed and validated on evaluation modules (TMC9660-STP-EVKIT, TMC5160-BOB, ADIN1200BCP32Z-R7, CAN-FD MAX33012EASA+) before being ported to the custom PCBs. Code will be committed here incrementally as each sub-system passes hardware-in-the-loop testing.

## Planned contents

- `vesper/` — STM32H743ZIT6 supervisory firmware: sensor fusion (EKF/EWMA), self-calibration engine, inverse kinematics, quintic trajectory planning, ADRC control loop, CAN-FD/Ethernet/USB-C communication stack.
- `fluxcruiser/` — STM32G431 actuator-node firmware: TMC9660 FOC interfacing over SPI, encoder/IMU readout, CAN-FD telemetry back to Vesper, end-effector servo and brake-chopper control.
- `drivers/` — Shared low-level drivers (TMC9660 SPI driver, MSC500/PMW3389 sensor drivers, CAN-FD messaging layer).
- `tests/` — Hardware-in-the-loop test scripts used during eval-module bring-up.

No functional firmware is guaranteed to run yet. If you're cloning this repo to reference the *design*, see the root [`README.md`](../../README.md) and the POC document instead — this folder will be updated as modules pass testing.

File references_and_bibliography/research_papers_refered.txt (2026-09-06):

https://www.analog.com/en/products/tmc5160.html
https://www.analog.com/en/products/tmc9660.html
https://www.analog.com/en/products/adis16470.html
https://www.analog.com/en/products/adin1200.html
https://www.analog.com/en/products/max33012e.html
https://www.researchgate.net/publication/287159662_Active_Disturbance_Rejection_Control_of_a_SCARA_Robot_Arm
https://www.st.com/en/microcontrollers-microprocessors/stm32h743-753.html
https://www.researchgate.net/publication/313547864_Two_Error_Models_for_Calibrating_SCARA_Robots_based_on_the_MDH_Model
https://www.sciencedirect.com/science/article/pii/S0007850607619222	
https://doi.org/10.1016/j.rcim.2012.06.001

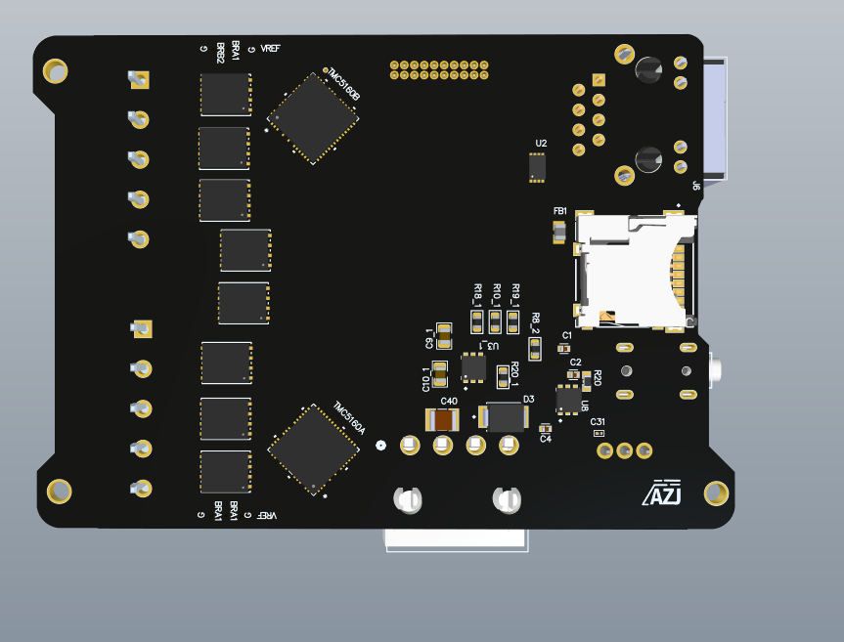
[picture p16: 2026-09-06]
pcb_and_schematics/VESPER-ONE_main_Controller/back-view.png

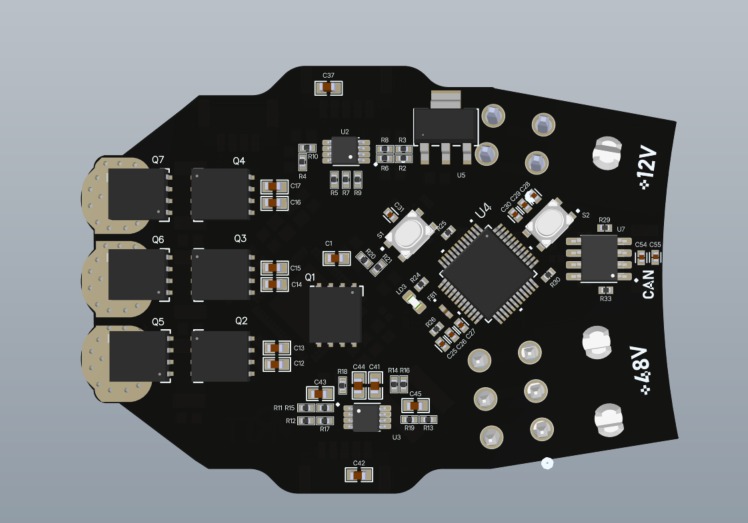
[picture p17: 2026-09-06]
pcb_and_schematics/FluxCruiser_Actuator_board/back-view.jpg

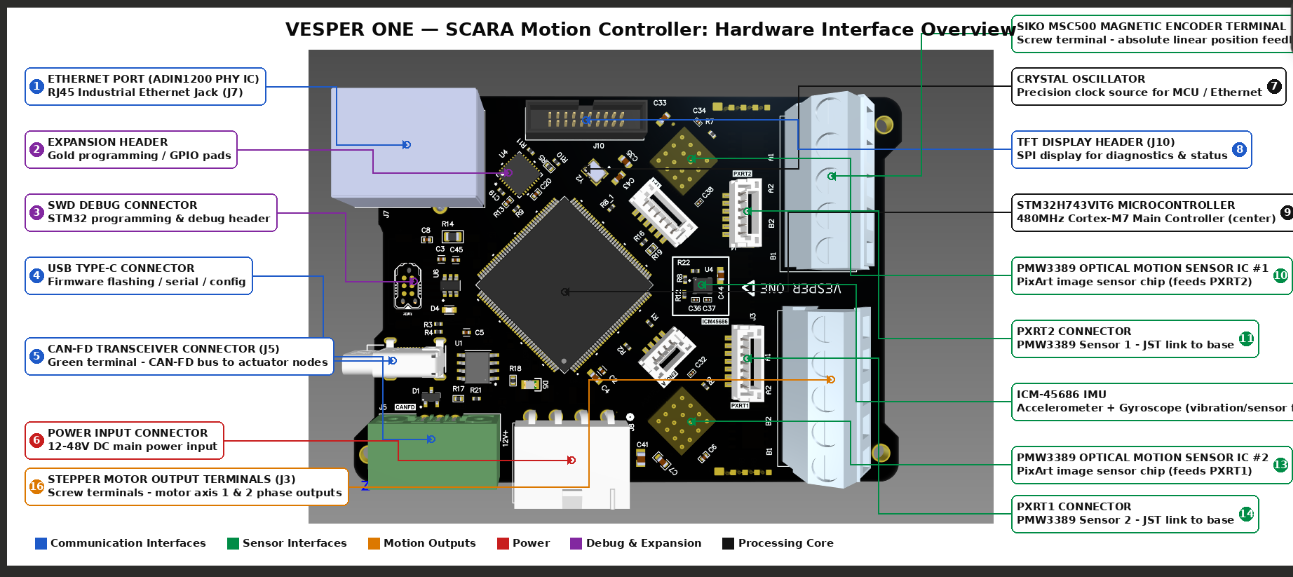
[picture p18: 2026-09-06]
pcb_and_schematics/VESPER-ONE_main_Controller/Board_connections.png

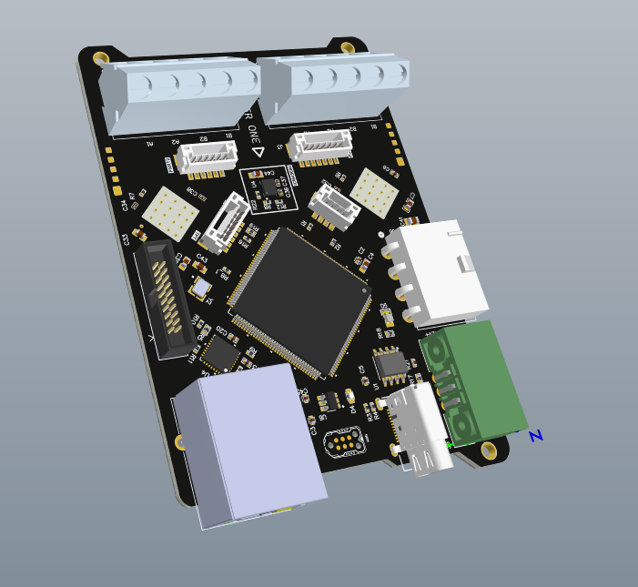
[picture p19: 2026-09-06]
pcb_and_schematics/VESPER-ONE_main_Controller/side-view.png

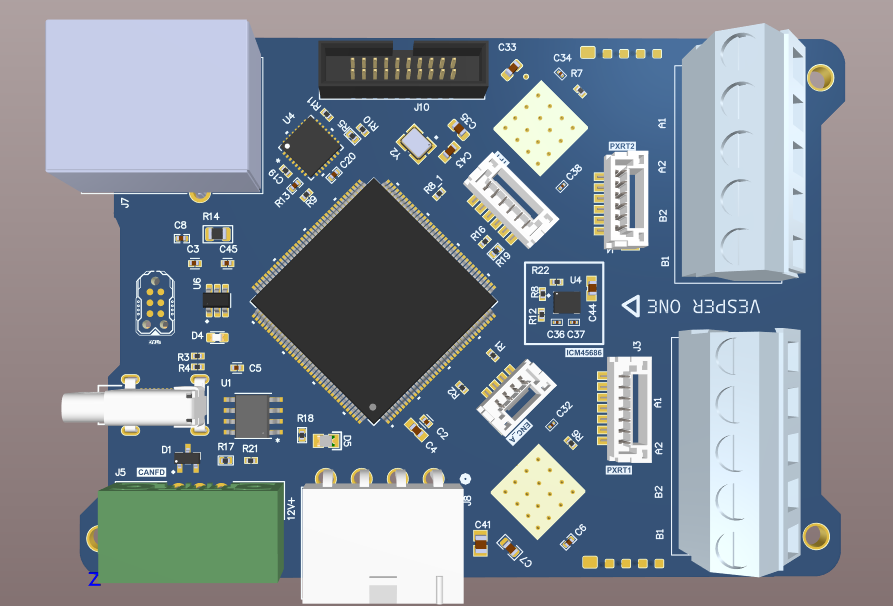
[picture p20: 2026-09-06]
pcb_and_schematics/VESPER-ONE_main_Controller/front-view.png

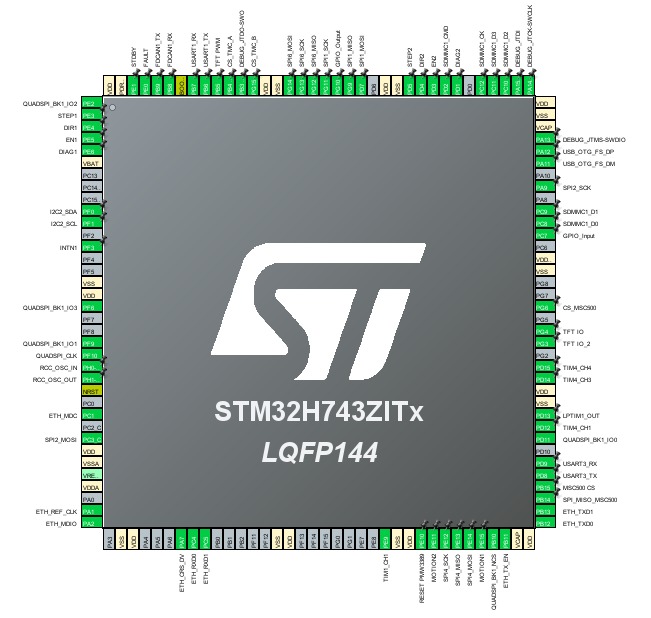
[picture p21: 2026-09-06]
pcb_and_schematics/VESPER-ONE_main_Controller/STM32H743 pin Config for Vesper.jpg

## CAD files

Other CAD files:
cad_files/SolidWorks_Package (2026 version compatible only)/linear_actuator.SLDASM
cad_files/SolidWorks_Package (2026 version compatible only)/BF15.SLDASM
cad_files/SolidWorks_Package (2026 version compatible only)/MG90S_assieme_disco_ldb2.SLDASM
cad_files/SolidWorks_Package (2026 version compatible only)/HGH20CAZ0C.SLDASM
cad_files/SolidWorks_Package (2026 version compatible only)/BK15.SLDASM
cad_files/SolidWorks_Package (2026 version compatible only)/gripper.SLDASM
cad_files/SolidWorks_Package (2026 version compatible only)/final_scara_prototype.SLDASM
cad_files/SolidWorks_Package (2026 version compatible only)/Test Linear Actuator.SLDASM
cad_files/SolidWorks_Package (2026 version compatible only)/HGR20 LINEAR GUIDE SUBASSEMBLY.SLDASM
cad_files/final_scara_prototype.STL
cad_files/SolidWorks_Package (2026 version compatible only)/gripper_base_plate.SLDPRT
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

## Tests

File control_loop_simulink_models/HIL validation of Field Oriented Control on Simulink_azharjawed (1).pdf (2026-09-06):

## Hardware-in-the-Loop Validation of Closed-Loop Field-Oriented Control

Designed and Implemented by : Azhar Jawed ( Email - azharjawed23773@gmail.com)

### Overview:

This project implements a Hardware-in-the-Loop (HIL) simulation framework for validating Field-Oriented Control (FOC) algorithms on an STM32G4 microcontroller using MATLAB/Simulink as the plant and motor behavior simulator.

The system is designed to emulate real-time BLDC/PMSM motor operation by generating simulated:

Three-phase current measurements (Ia, Ib, Ic)
Electrical rotor angle (θe)
Dynamic torque and RPM responses

These parameters are continuously adjusted based on:

Required RPM setpoint
Torque demand
PID controller response
Simulated motor load conditions

This creates a realistic environment for testing the hardware design of our FOC speed controller without requiring physical motor hardware while also helping with its firmware.

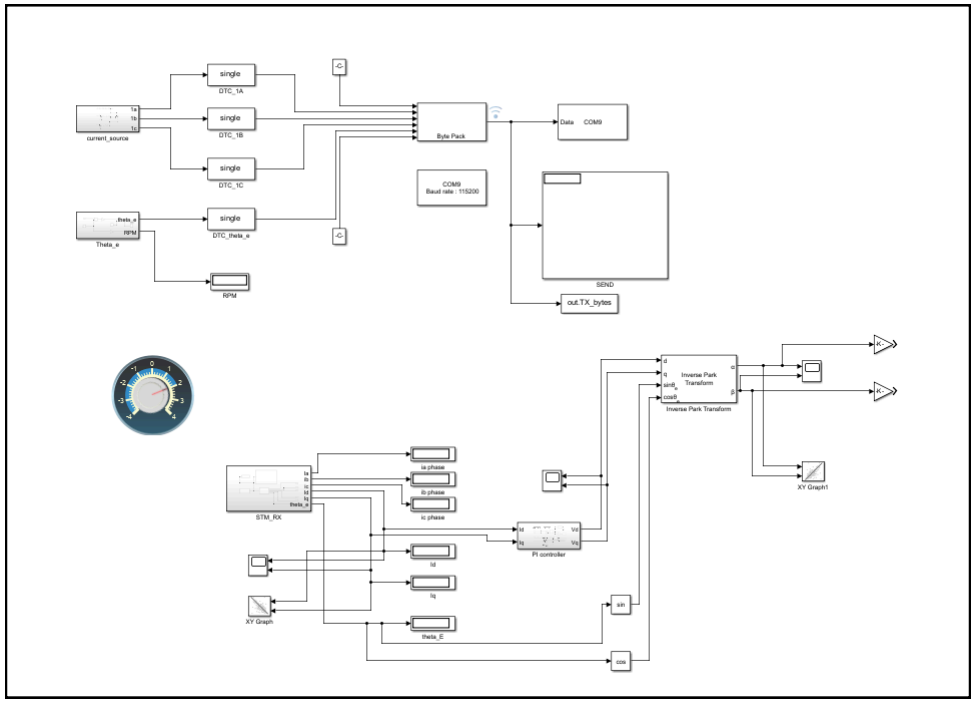
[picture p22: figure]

Complete HIL model for Field Oriented Control Implementation on Simulink

# System workflow:

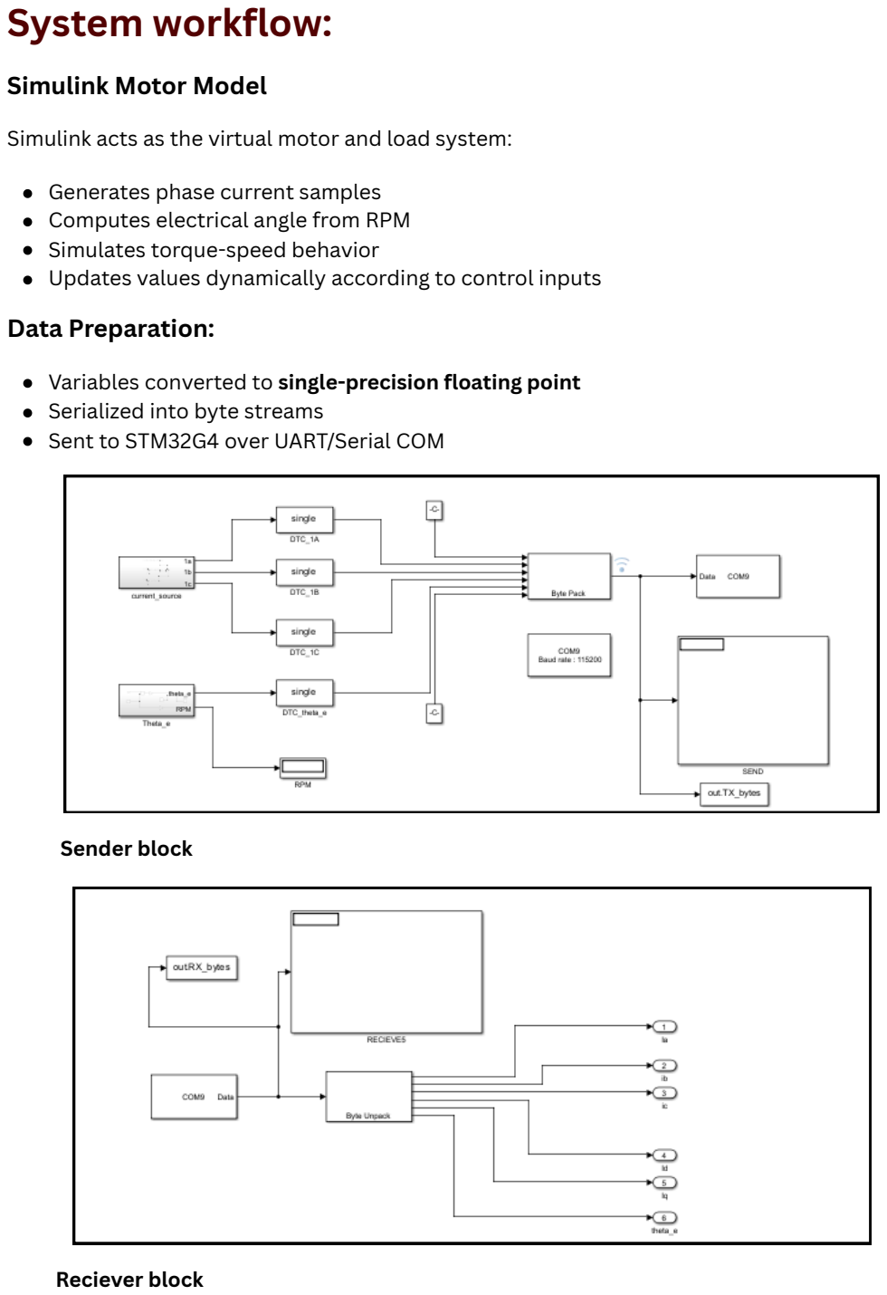
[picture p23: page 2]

Simulink Motor Model

Simulink acts as the virtual motor and load system:

Generates phase current samples
Computes electrical angle from RPM
Simulates torque-speed behavior
Updates values dynamically according to control inputs Data Preparation:

Variables converted to single-precision floating point Serialized into byte streams
Sent to STM32G4 over UART/Serial COM

Sender block

Reciever block

## 2. STM32G431 Embedded Controller

The STM32G431 performs core FOC mathematical operations: Processing Steps:

UART data reception
Incoming byte stream unpacking into single-precision current and electrical angle variables (Ia, Ib, Ic, θ_e)
Real-time reconstruction of motor state variables
Clarke Transformation (abc → αβ frame)
Park Transformation (αβ → dq rotating frame)
Extraction of direct-axis current (Id) for flux control
Extraction of quadrature-axis current (Iq) for torque control
Repackaging processed dq values into byte streams
UART transmission back to Simulink for closed-loop PID control, monitoring, and visualization
Byte unpacking / decoding
Clarke Transformation
Park Transformation
Id and Iq current extraction
Returns processed values to Simulink for monitoring

Returned Variables: Direct-axis current (Id), Quadrature-axis current (Iq) , Control loop outputs

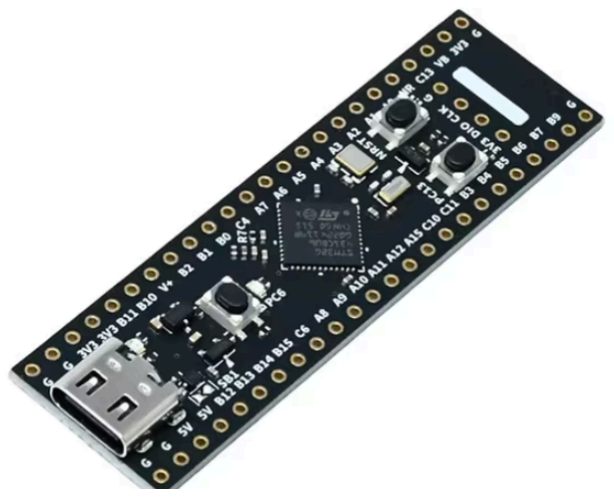
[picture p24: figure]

STM32G431CBU6 is a mainstream Arm Cortex-M4 32-bit MCU with
DSP and FPU instructions, offering 170 DMIPS / 213 CoreMark performance, high-speed ADCs, and advanced control timers. It is optimized for motor control, digital power conversion, and closed-loop control applications such as Field-Oriented Control (FOC).

## 3. Closed-Loop Control in Simulink

Returned Id and Iq values are used in:

PID torque controller
Speed controller
Torque reference tracking
After controller error correction applied : Inverse Park Transform applied Produces Vα, Vβ

# Mathematical Relations

## Relationship Between Electrical Speed and Theta in RPM

The connection between electrical speed and theta in RPM is essential for generating realistic values of electrical angles without a physical load. The accuracy of this relationship can be demonstrated through the X/Y plot of ( i_d ) and ( i_q ), which results in an elliptical shape.

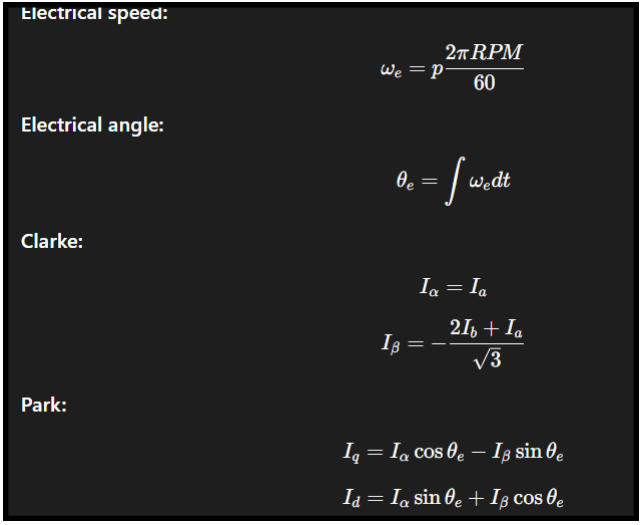
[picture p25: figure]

The graph can be observed in the accompanying video. Since the values of Id and Iq, calculated and transmitted by the STM32G431 microcontroller unit (MCU), have been mathematically verified, we will now proceed with PI tuning to optimize our desired torque output.

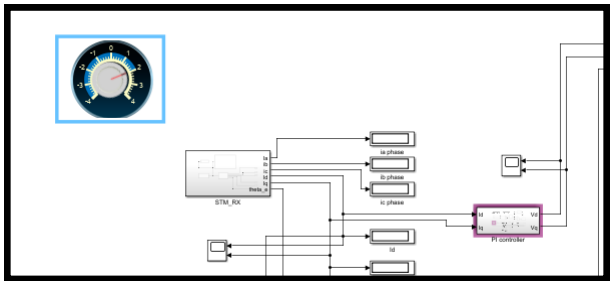
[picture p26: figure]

## Error Correction & PI Parameter Tuning

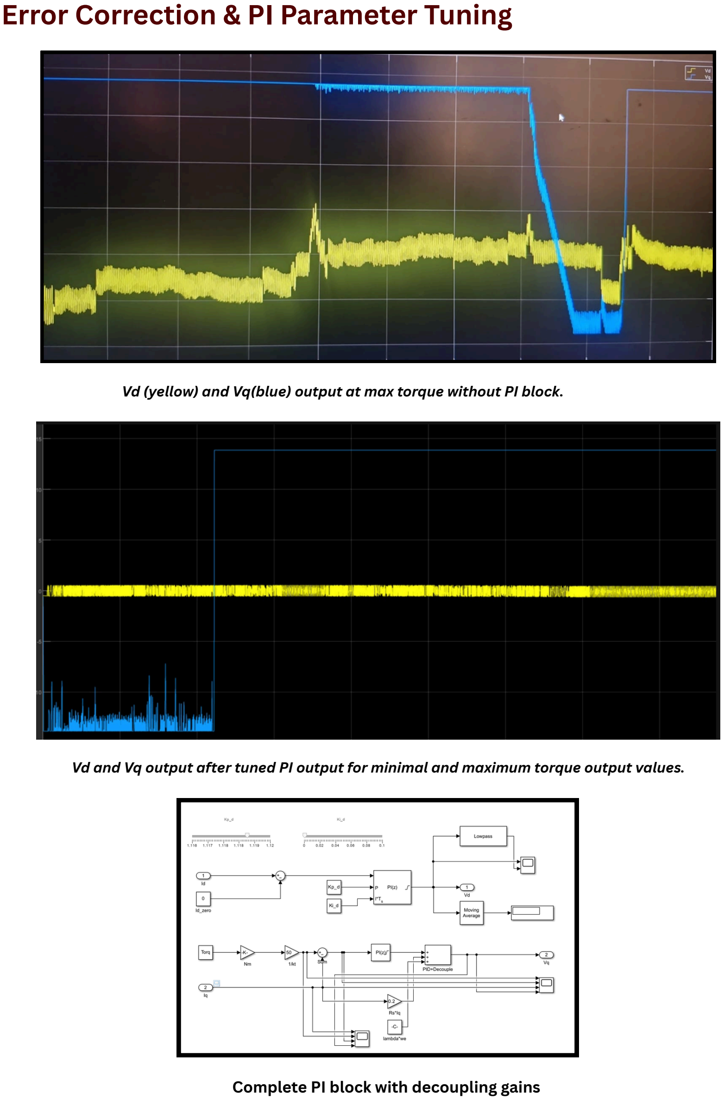
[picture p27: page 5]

Vd (yellow) and Vq(blue) output at max torque without PI block.

Vd and Vq output after tuned PI output for minimal and maximum torque output values.

Complete PI block with decoupling gains

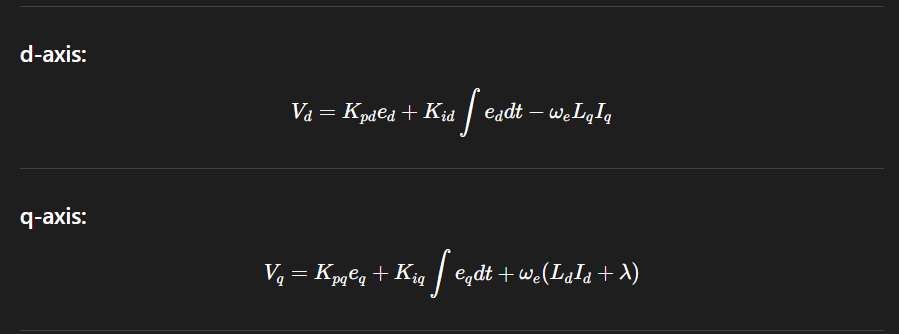
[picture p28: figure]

I also included the decoupling terms that are contingent upon the motor's construction. For this simulation, I utilized the characteristics of the T200 thruster from Blue Robotics, which is an industrial-grade thruster designed for underwater applications.

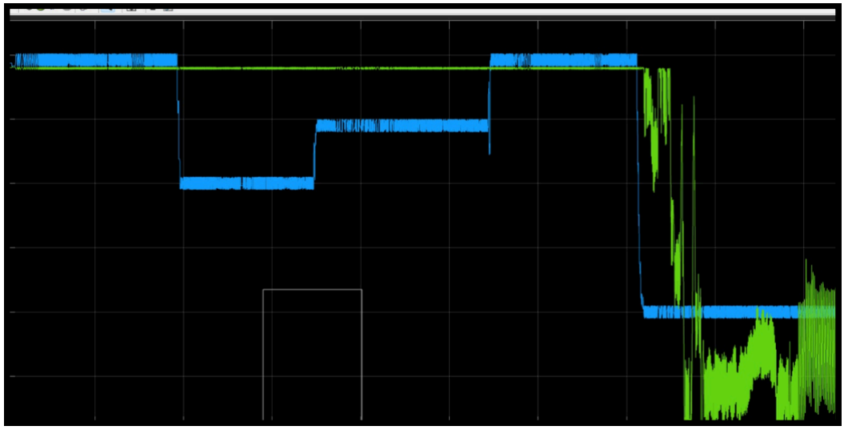
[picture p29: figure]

One of the most impressive graphs produced via this project : The blue trace represents the q-axis current error (difference between the commanded Iq reference derived from torque input and the measured Iq feedback from the STM32), while the green trace shows the PI controller output voltage Vq, including decoupling terms. As torque commands step through different values, the controller adjusts Vq to minimize current error and maintain closed-loop stability

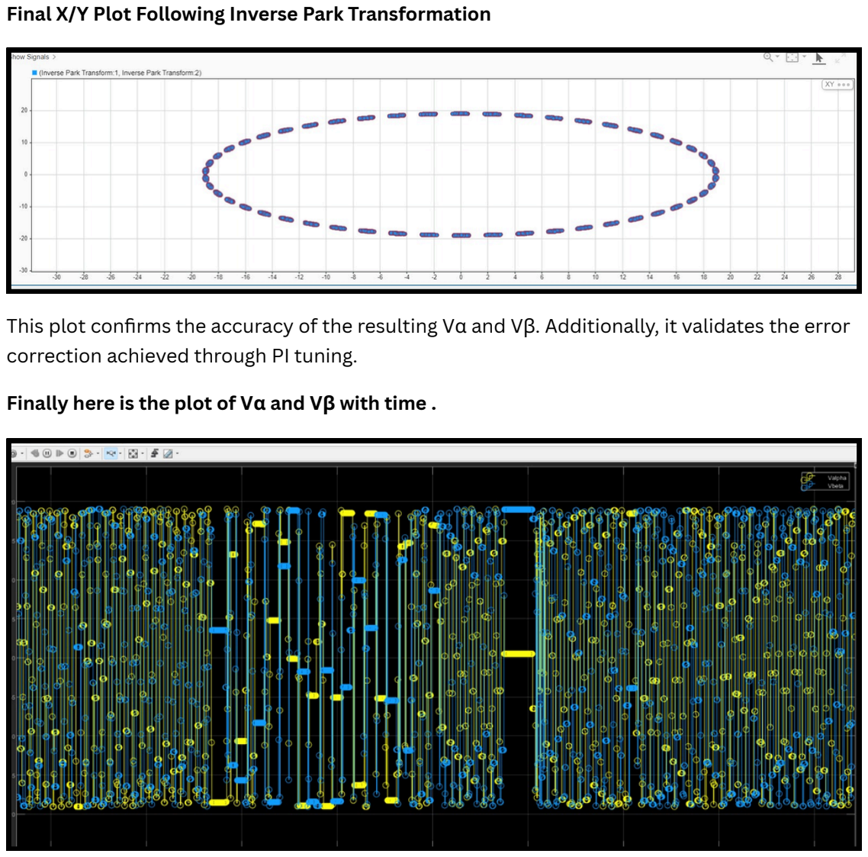
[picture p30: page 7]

Final X/Y Plot Following Inverse Park Transformation

This plot confirms the accuracy of the resulting Vα and Vβ. Additionally, it validates the error correction achieved through PI tuning.

Finally here is the plot of Vα and Vβ with time .

# Is this verification sufficient?

In the Hardware-in-the-Loop (HIL) phase, confirming the generated Vα (Vₐ) and Vβ (Vᵦ) outputs is sufficient to verify the proper operation of the Field-Oriented Control (FOC) model. These two variables encapsulate the entire synthesized stator voltage vector within the stationary reference frame. After Inverse Park transformation , all control actions (PI controllers , current sensing , Torque commands, rotor electrical speed) are condensed into this equation :

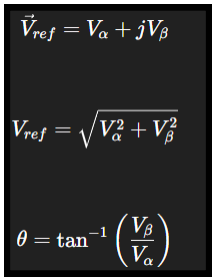
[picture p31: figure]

Using these values, Space Vector PWM timing can be reconstructed:


and for a single sector , the duty cycles calculated are :


Consequently, the resulting duty cycle is intrinsically dependent on the Vα (Vₐ) and Vβ (Vᵦ) values we have accurately generated in real-time using the STM32 and the simulated input for our desired torque. By checking Vα (Vₐ) and Vβ (Vᵦ), the project creates a control core that works with any hardware. This core can move easily between different embedded systems without needing to change the main FOC algorithm. These outputs define the reference voltage vector, so they can work with various microcontrollers, PWM parts, and gate drivers.

Moreover, they help in making real-time plots to study efficiency and find any problems in a new closed-loop algorithm on a different hardware. In Future , I will be adding blocks of DRV series gate drivers and motor models for simulation and testing the hardware of my own closed loop speed controller.

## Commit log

2026-09-06 Add InkCat SCARA project with LFS-tracked CAD and video files
2026-09-06 Add full InkCat SCARA project files
    [AS 1420 - 1973 - M3 x 10.SLDPRT, AS 1427 - M2 x 12.SLDPRT, BF15.SLDASM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]
